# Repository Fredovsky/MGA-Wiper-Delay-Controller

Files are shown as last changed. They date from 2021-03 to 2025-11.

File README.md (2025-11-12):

# Classic Car Intermittent Wiper Motor Controller

A fully customizable, Arduino-based, multi-frequency intermittent wiper controller for classic British cars with single-speed Lucas DR2 wiper motors. This controller is non-destructive and fully reversible, requiring no modifications to the original vehicle.

## Overview

Some classic British cars such as the MG MGA and Triumph TR2 came equipped with a single-speed Lucas DR2 wiper motor. When encountering rain of various intensity, the single speed is just not appropriate 90% of the time. This project provides an intelligent controller that adds intermittent wiper functionality without modifying the original vehicle or requiring additional switches.

Video Title (https://www.youtube.com/watch?v=Cxpz3yVJnDE)

### Key Features

- **Non-destructive installation** - No modifications to the original vehicle
- **Uses factory switch** - No need for additional controls or multi-position switches
- **Multiple intermittent speeds** - Four configurable delay settings plus continuous mode
- **Intuitive control** - Quick ON-OFF-ON toggles to cycle through speeds
- **Compact design** - Small SMD-based PCB fits under the dashboard
- **Arduino-based** - Easy to program and customize
- **Fully reversible** - Can be removed and wiring restored to factory configuration

## The Problem

The Lucas DR2 wiper motor found in many classic British cars from the 1950s and 1960s operates at only a single, continuous speed. When driving through light rain at moderate/slow speeds, this continuous wiping motion is often too frequent. Many drivers end up manually switching the wipers ON and OFF repeatedly to achieve the desired intermittent wiping - this project automates that process.

### Original Wiper System

The factory wiper system has three terminals:
- **Terminal 2**: Continuous +12V power
- **Terminal 1**: Ground connection via dashboard switch
- **Terminal E**: Auto-parking ground connection

When the dashboard switch grounds terminal 1, the motor starts. The motor continues running via terminal E until the wipers return to their parked position, regardless of the switch position. If the switch is still closed when parked, wiping continues; otherwise, the motor stops.

## Solution

This controller sits between the original dashboard switch and the wiper motor, interpreting the switch position to provide multiple intermittent wiper modes. The driver uses quick ON-OFF-ON toggles of the original switch to cycle through different intermittent speeds.

### Operation Modes

The controller provides five operating modes:

1. **Intermittent 1**: Wipes every 10 seconds (slowest)
2. **Intermittent 2**: Wipes every 7.5 seconds
3. **Intermittent 3**: Wipes every 5 seconds
4. **Intermittent 4**: Wipes every 2.5 seconds
5. **Continuous**: Original single-speed operation (fastest)

### User Interface

- **Activate wipers**: Pull the switch ON to start wipers at the slowest intermittent setting
- **Increase speed**: Quickly toggle the switch OFF then ON (within 2 seconds) to advance to the next faster setting
- **Turn off wipers**: Push the switch OFF and hold for more than 2 seconds to deactivate and reset
- **Next activation**: Always starts at the slowest intermittent setting after a reset

## Hardware Design

### Architecture

The controller consists of three main sections:

1. **Power Regulation**: 12V to 5V conversion for microcontroller operation
2. **Microcontroller**: ATtiny85 running Arduino framework code
3. **Relay Driver**: High-current relay to control the wiper motor (5-10A capability)

### Components

#### Main Components

| Component | Part Number | Description | Quantity |
|---|---|---|---|
| **Microcontroller** | ATtiny85-20SU | 8-bit MCU, 8K Flash, Arduino compatible | 1 |
| **Voltage Regulator** | LM2931DT-5.0G | 5V 100mA LDO with load dump protection | 1 |
| **Relay** | V23076A1001C133 | Automotive power relay | 1 |
| **Transistor** | BC846BLT1G | NPN transistor for relay driver | 1 |
| **Optocoupler** | SFH6186-3T | Isolation for switch input | 1 |

#### Passive Components

| Component | Part Number | Description | Quantity |
|---|---|---|---|
| **Ferrite Beads** | FBMJ2125HS420-T | 0805 42Ω current chip bead | 2 |
| **Rectifier Diodes** | CGRTS4007-HF | 1000V 1A SMD rectifier | 2 |
| **Zener Diode** | SZMMSZ33ET1G | 33V 0.5W voltage regulator | 1 |
| **C1** | C0603C473K3RACTU | 0.047µF 25V X7R 0603 | 1 |
| **C2** | CGA4J1X7S1E106K125AC | 10µF 25V 0805 | 1 |
| **C3** | GRM21BC71C106KE11L | 10µF 16V X7S 0805 | 1 |
| **C4** | 35ZLH100MEFC6.3X11 | 100µF electrolytic capacitor | 1 |
| **C5, C6** | C0603C104K3RAC3190 | 0.1µF 25V X7R 0603 | 2 |
| **R1** | CRGP2512F470R | 470Ω 1% 2512 SMD | 1 |
| **R2, R3** | ERJ-3EKF1002V | 10kΩ 1% 0603 | 2 |
| **R4** | ERJ-3EKF1001V | 1kΩ 1% 0603 | 1 |

#### Connectors

| Component | Part Number | Description | Quantity |
|---|---|---|---|
| **J1-J4** | 7799 | M4 screw terminals | 4 |
| **J5** | 10129381-906004BLF | 2×3 ISP programming header | 1 |

### PCB Design

The PCB uses primarily SMD components to minimize size and was designed to potentially mount directly to the wiper motor housing. The final implementation installs under the dashboard where it remains virtually invisible while maintaining the stock appearance of the vehicle.

**PCB Specifications:**
- Compact two-layer design
- SMD components (0603/0805) where possible
- Through-hole components for high-current connections
- ISP programming header for easy firmware updates

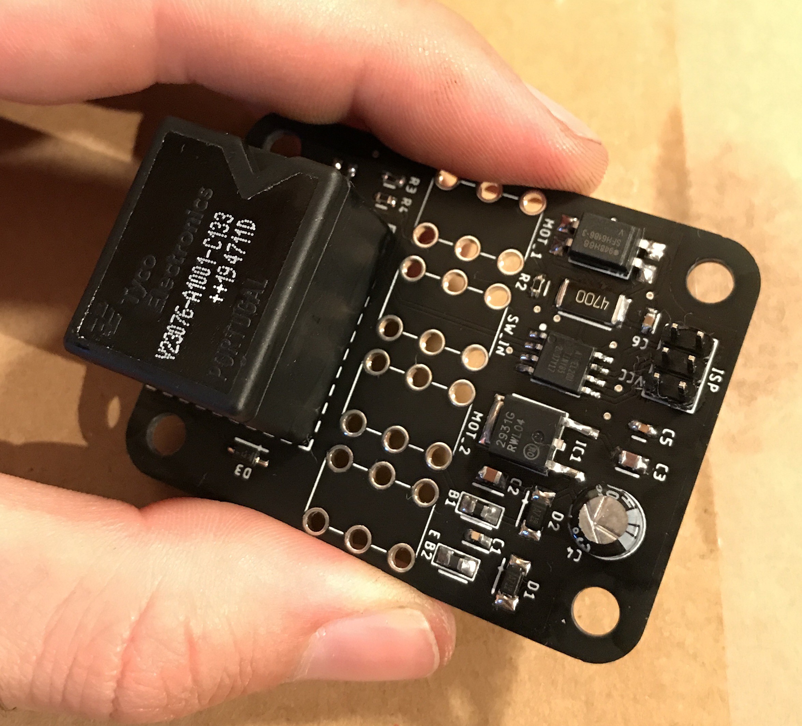
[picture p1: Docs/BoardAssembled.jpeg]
PCB Assembled


### Enclosure

The controller is housed in a two-part snap-fit enclosure designed in Fusion 360. Originally intended to mount on the wiper motor housing, the final installation places it under the dashboard for easier access and installation.

## Software

The controller is programmed using the Arduino framework with the ATtiny85 core. The code implements:

- **Switch debouncing** in software (50ms delay)
- **Non-blocking timing** using `millis()` instead of `delay()`
- **Toggle detection** to cycle through intermittent speeds

### Key Parameters

```cpp
// I/O Configuration
#define PIN_WIPER_OUTPUT 3          // Relay control pin
#define PIN_INPUT_SWITCH 4          // Dashboard switch input pin
#define SWITCH_DEBOUNCE_DELAY_MS 50 // Debounce delay
#define TOGGLE_LIMIT_DELAY 2000     // Max time for toggle detection

// Intermittent Delays
#define INTERMITTENT_1_MS 10000     // 10 seconds
#define INTERMITTENT_2_MS 7500      // 7.5 seconds
#define INTERMITTENT_3_MS 5000      // 5 seconds
#define INTERMITTENT_4_MS 2500      // 2.5 seconds

// Motor Control
#define RELAY_TIME_MS 500           // Relay activation duration
```

### Software Architecture

The software consists of two main functions:

#### `loop()` Function
- Reads the dashboard switch state
- Implements software debouncing
- Detects state changes (ON→OFF, OFF→ON)
- Tracks toggle sequences to determine mode changes

#### `wipe()` Function
- Executes wiper control based on current mode
- Manages timing for intermittent delays
- Controls relay activation/deactivation

### Customization

The intermittent delays can be easily customized by modifying the `INTERMITTENT_X_MS` definitions. The values are in milliseconds, so adjusting them to your preference is straightforward.

## Installation

### Wiring

The controller installs inline between the original wiring harness and the wiper motor:

**Input (from vehicle harness):**
- J1: Ground from dashboard switch
- J2: +12V power
- J3: Parking switch connection

**Output (to wiper motor):**
- J3: To motor terminal 1
- J2: To motor terminal 2 (through controller)
- J4: To motor terminal E

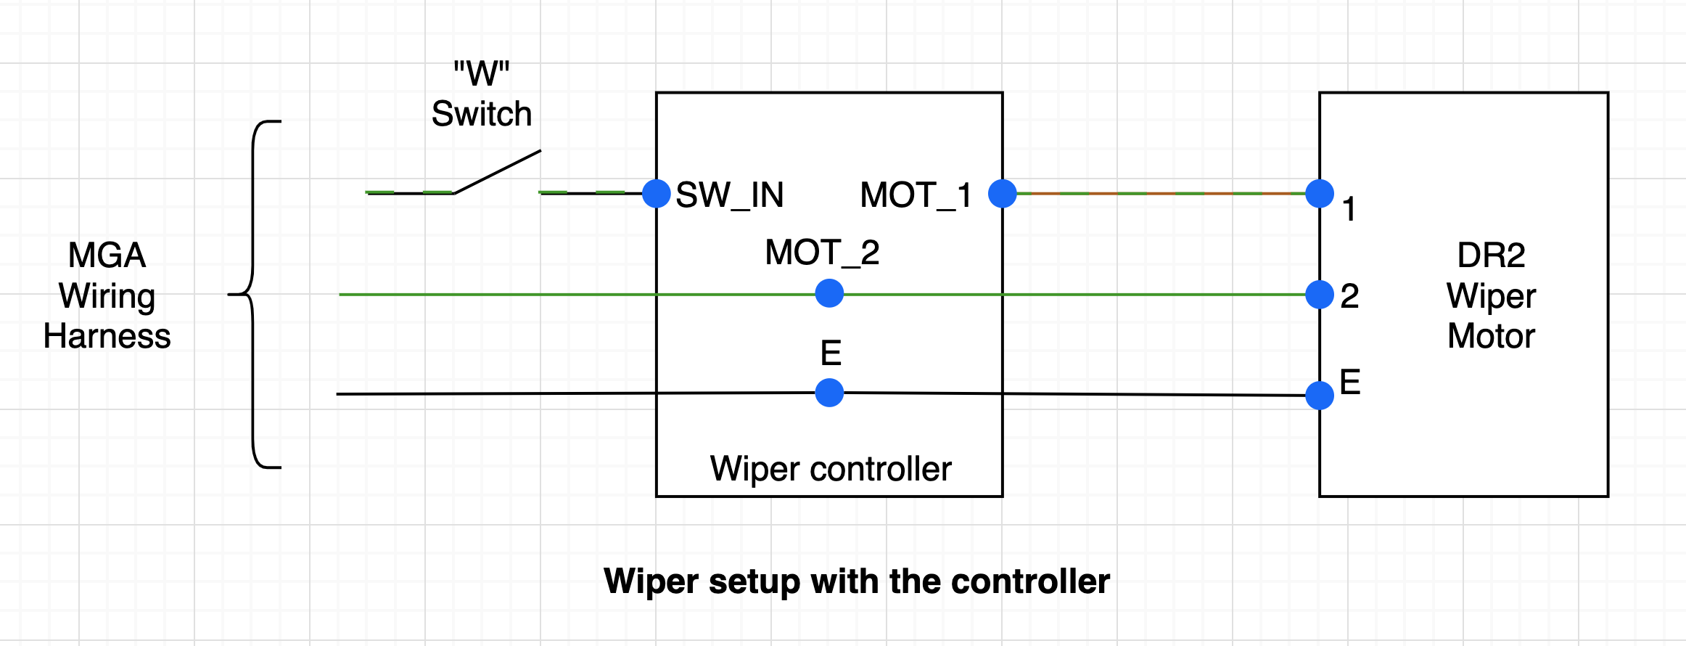
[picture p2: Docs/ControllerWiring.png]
PCB Wiring

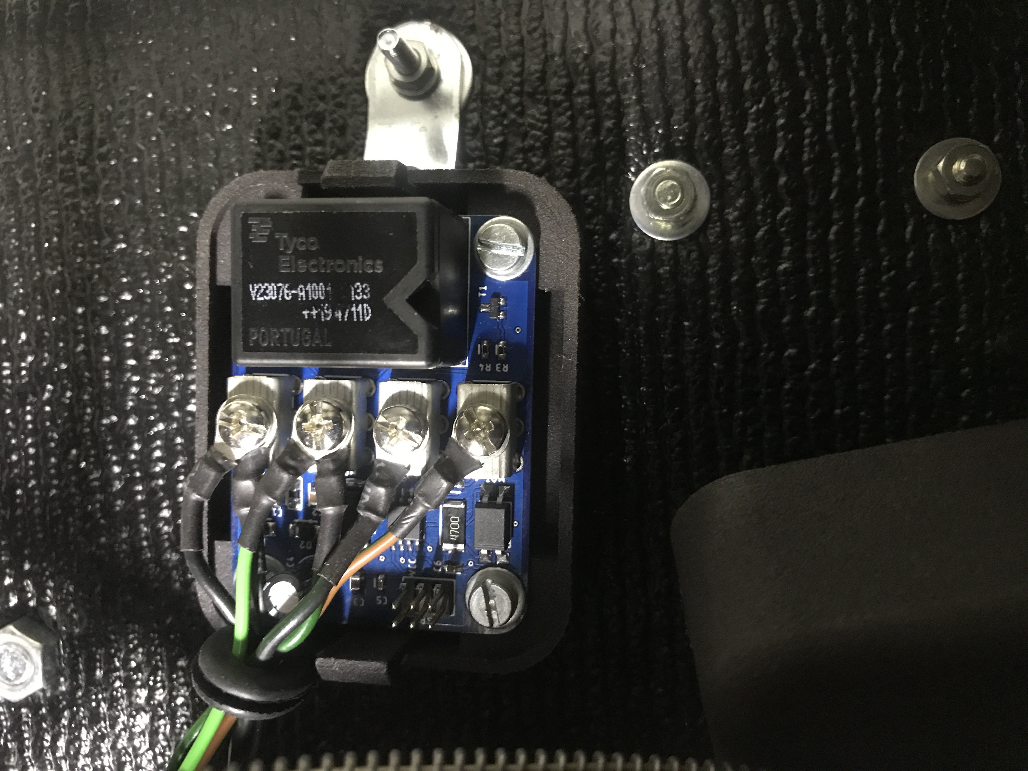
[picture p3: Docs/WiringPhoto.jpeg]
PCB Wiring Photo


### Programming

The ATtiny85 can be programmed via the ISP header (J5) using:
- USBasp programmer
- Arduino as ISP
- Other AVR programmers supporting ISP protocol

Flash the provided Arduino sketch to the ATtiny85 using the ISP connector on the PCB.

### Physical Installation

1. Disconnect the battery negative terminal
2. Locate the wiper motor and disconnect the original three-wire connector
3. Connect the controller inline between the harness and motor
4. Mount the controller under the dashboard using zip ties or mounting brackets
5. Reconnect the battery and test operation

## Testing

After installation, verify operation:

1. **Power on**: Pull the wiper switch - wipers should activate in slowest intermittent mode
2. **Toggle test**: Quickly switch OFF then ON - wipers should advance to next speed
3. **All modes**: Cycle through all five modes to verify each speed
4. **Reset**: Hold switch OFF for 3+ seconds, then reactivate - should start at slowest speed
5. **Parking**: Turn off in any mode - wipers should return to parked position

## Performance

The controller has been successfully tested and installed in an MG MGA. Key observations:

- **Reliable operation**: No false triggers or missed toggles
- **Proper timing**: All intermittent delays work as programmed
- **Original functionality preserved**: Can be removed without trace
- **Invisible installation**: Maintains stock appearance

## Files and Resources

All project files are available in this repository:
- `PlatformIO/` - Arduino source code
- `Eagle/` - Schematics, PCB layouts (+Gerber files)
- `Enclosure/` - 3D printable enclosure designs (STL/STEP files)

## Bill of Materials

Complete BOM with supplier part numbers is available in the `Eagle/BOM_Wiper_Control.pdf` file. All components are readily available from Mouser Electronics and other major suppliers.

## Requirements

### Hardware Requirements
- Classic car with Lucas DR2 or similar single-speed wiper motor
- Original single-pole ON-OFF wiper switch
- 12V electrical system

### Software Requirements
- Arduino IDE or PlatformIO
- ATtiny core support (install via Board Manager)

### Programming Tools
- AVR programmer with ISP support (USBasp or Arduino ISP programmer)
- 6-pin ISP cable

## Design Considerations

### Non-Destructive Philosophy
Every aspect of this design prioritizes reversibility:
- No cutting or drilling of original components
- No permanent wiring modifications
- No changes to dashboard or switch
- Controller can be completely removed, returning vehicle to factory specification

### Automotive Environment
The design accounts for the harsh automotive environment:
- Load dump protection in voltage regulator
- Automotive-grade relay rated for motor inrush current
- Ferrite beads for EMI suppression
- Proper wire gauge for current handling

### Safety
- Relay rated well above motor current draw
- Fused power connection recommended
- Isolated optocoupler for switch input
- Zener diode for voltage spike protection

## Compatibility

This controller is designed for the Lucas DR2 wiper motor but should work with any single-speed wiper motor that uses a similar three-wire configuration with auto-parking functionality. Confirm your motor's wiring matches before installation.

**Known compatible vehicles:**
- MG MGA (1955-1962)
- Triumph TR2 (1953-1955)
- Triumph TR3 (1955-1962)
- Other British cars from the 1950s-1960s with Lucas DR2 motors

## Contributing

Contributions are welcome! If you've installed this controller in a different vehicle or made improvements to the design, please submit a pull request or open an issue.

## License

This project is licensed under the **Creative Commons Attribution-NonCommercial-ShareAlike 4.0 International License (CC BY-NC-SA 4.0)**.

### You are free to:
- **Share** — copy and redistribute the material in any medium or format
- **Adapt** — remix, transform, and build upon the material

### Under the following terms:
- **Attribution** — You must give appropriate credit, provide a link to the license, and indicate if changes were made
- **NonCommercial** — You may not use the material for commercial purposes
- **ShareAlike** — If you remix, transform, or build upon the material, you must distribute your contributions under the same license

### What this means:
✅ **Allowed:**
- Personal use and modifications
- Educational purposes
- Sharing with the classic car community
- Building your own controller for your vehicle
- Sharing improvements and modifications

❌ **Not Allowed:**
- Selling the controller or kits commercially
- Manufacturing for profit
- Including in commercial products or services
- Using the design in commercial automotive products

**Full License:** [CC BY-NC-SA 4.0](https://creativecommons.org/licenses/by-nc-sa/4.0/)



## Acknowledgments

- **MGAGuru** for excellent wiper motor documentation
- **Arduino community** for ATtiny85 core support
- **Hackaday.io community** for feedback and encouragement

## Author

Created by F. Lidove for the classic car community.

Hackaday.io Project: https://hackaday.io/project/175605-classic-car-intermittent-wiper-motor-controller

## Disclaimer

This modification involves working with automotive electrical systems. While designed to be safe and reversible, improper installation could potentially damage your vehicle's electrical system. Install at your own risk. The author assumes no liability for any damage resulting from the use of this design.

Always disconnect the battery before working on automotive electrical systems.

## Support

For questions, issues, or discussions:
- Open an issue on this GitHub repository
- Comment on the Hackaday.io project page

---

*Enjoy safer driving in light rain with your classic British car!*

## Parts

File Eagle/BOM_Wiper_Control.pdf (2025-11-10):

WIPER CONTROL
N° Mouser | N° de fab. | Fabricant | N° client | Description
863-SZMMSZ33ET1G | SZMMSZ33ET1G | onsemi | D3 | Diodes Zener REG 0.5W 33V SPCL
963-FBMJ2125HS420-T | FBMJ2125HS420-T | TAIYO YUDEN | FB1 FB2 | Perles de ferrite 963-LSMCC201208T420R RPLCMT PN 0805 42OHMS 25%
750-CGRTS4007-HF | CGRTS4007-HF | Comchip Technology | D1 D2 | Redresseurs SMD 1000V 1A
863-LM2931DT-5.0G | LM2931DT-5.0G | onsemi | IC1 | Régulateurs de tension LDO 5V 100mA w/Load Dump
232-35ZLH100MEFC63X1 | 35ZLH100MEFC6.3X11 | Rubycon | C4 | Condensateurs électrolytiques en aluminium - Fils radiaux LOW IMPEDANCE ELECTROLYTIC CAPACITORS
810-CGA4J1X7S1E106K1 | CGA4J1X7S1E106K125AC | TDK | C2 | Condensateurs céramique multicouches MLCC - CMS 0805 25VDC 10uF 10% AEC-Q200
81-GRM21BC71C106KE1L | GRM21BC71C106KE11L | Murata | C3 | Condensateurs céramique multicouches MLCC - CMS 10 uF 16 VDC 10% 0805 X7S
556-ATTINY85-20SU | ATTINY85-20SU | Microchip | U1 | Microcontrôleurs 8 bits - MCU AVR 8K FLSH 512B EE 512B SRAM ADC 5V
80-C0603C104K3R3190 | C0603C104K3RAC3190 | KEMET | C5 C6 | Condensateurs céramique multicouches MLCC - CMS 25V 0.1uF X7R 0603 10% AEC-Q200
571-V23076A1001C133 | V23076A1001C133 | TE Connectivity | RL1 | Relais pour automobile Power Relay K
80-C0603C473K3R | C0603C473K3RACTU | KEMET | C1 | Condensateurs céramique multicouches MLCC - CMS 25V 0.047uF X7R 0603 10%
667-ERJ-3EKF1001V | ERJ-3EKF1001V | Panasonic | R4 | Résistances à couches épaisses - CMS 0603 1Kohms 1% AEC-Q200
863-BC846BLT1G | BC846BLT1G | onsemi | T1 | Transistors bipolaires - BJT 100mA 80V NPN
649-1012938190604BLF | 10129381-906004BLF | Amphenol | J5 | Embases et logements de câbles ECONOSTIK HEADER DR VT TH 2X3
667-ERJ-3EKF1002V | ERJ-3EKF1002V | Panasonic | R2 R3 | Résistances à couches épaisses - CMS 0603 10Kohms 1% AEC-Q200
782-SFH6186-3T | SFH6186-3T | Vishay | OK1 | Optocoupleurs de sortie de transistor Phototransistor Out Single CTR 100-200%
279-CRGP2512F470R | CRGP2512F470R | TE Connectivity | R1 | Résistances à couches épaisses - CMS CRGP 2512 470R 1% SMD Resistor
563-CU-18425-B | CU-18425-B | Bud Industries | ENCL | Boîtiers, boîtes et coffrets Snap Utility Box Black (2.8 X 2 X 1.7 In)
534-7799 | 7799 | Keystone Electronics | J1-J4 | Bornes M4 Screw term- H.D.

1

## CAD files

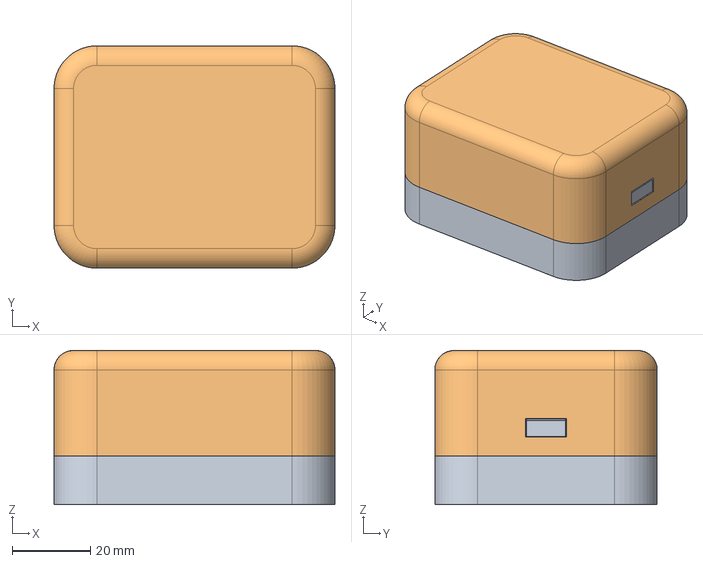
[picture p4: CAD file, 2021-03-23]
Enclosure/Snap Fit Box.stp
72.0 x 57.0 x 39.5 mm

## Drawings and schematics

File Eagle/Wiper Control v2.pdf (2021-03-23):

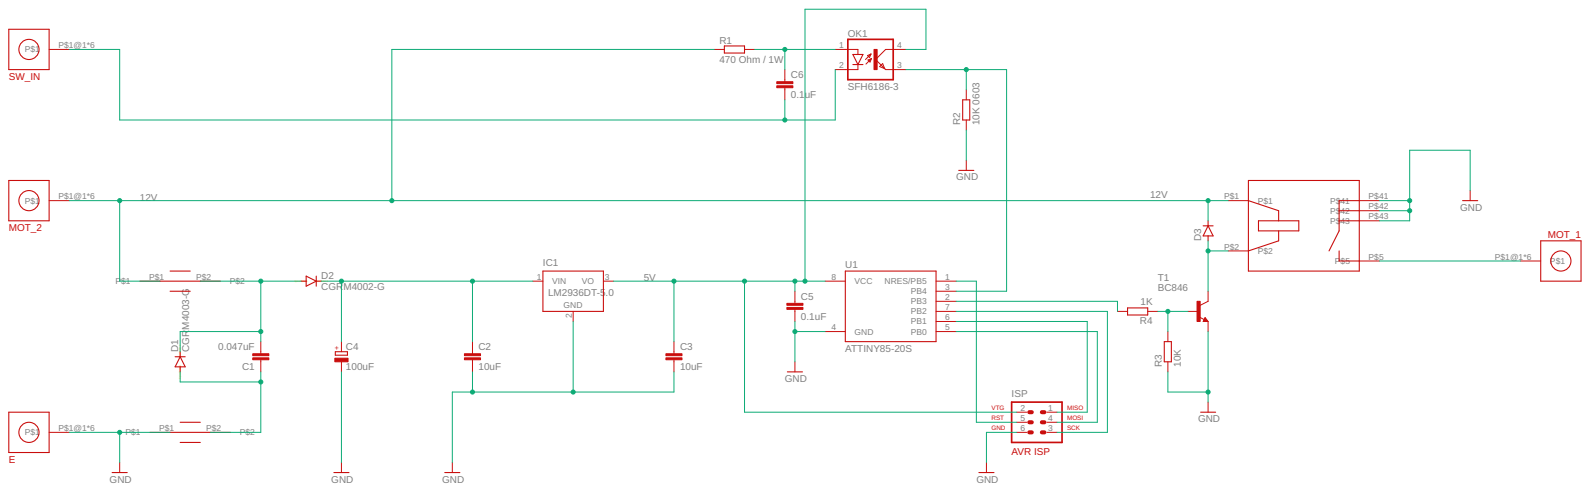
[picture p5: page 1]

SpiceOrder 1 SpiceOrder 2 SpiceOrder 1 SpiceOrder 2 LM2936DT-5.0 CGRM4003-G 0.047uF CGRM4002-G 10uF 10uF GND GND 100uF GND ATTINY85-20S GND GND 0.1uF BC846 GND SFH6186-3 GND 470 Ohm / 1W 10K 0603 10K 1K 0.1uF GND GND VIN 1 VO 3 2 IC1 P$1 P$1 P$2 P$2 P$1 P$1 P$2 P$2 D1 C1 D2 C4 C2 C3 PB0 5 PB1 6 PB2 7 PB3 2 PB4 3 NRES/PB5 1 VCC 8 GND 4 U1 3 25 1 6 4 ISP C5 P$1 P$1 P$2 P$2 P$41 P$41 P$5 P$5 P$42 P$42 P$43 P$43 T1 12 34 OK1 R1 R2 D3 R3 R4 C6 P$1 P$1@1*6 P$1 P$1@1*6 P$1 P$1@1*6 P$1 P$1@1*6 5V 12V 12V + AVR ISP MOSI SCK VTG MISO RST GND EMOT_2 SW_IN MOT_1

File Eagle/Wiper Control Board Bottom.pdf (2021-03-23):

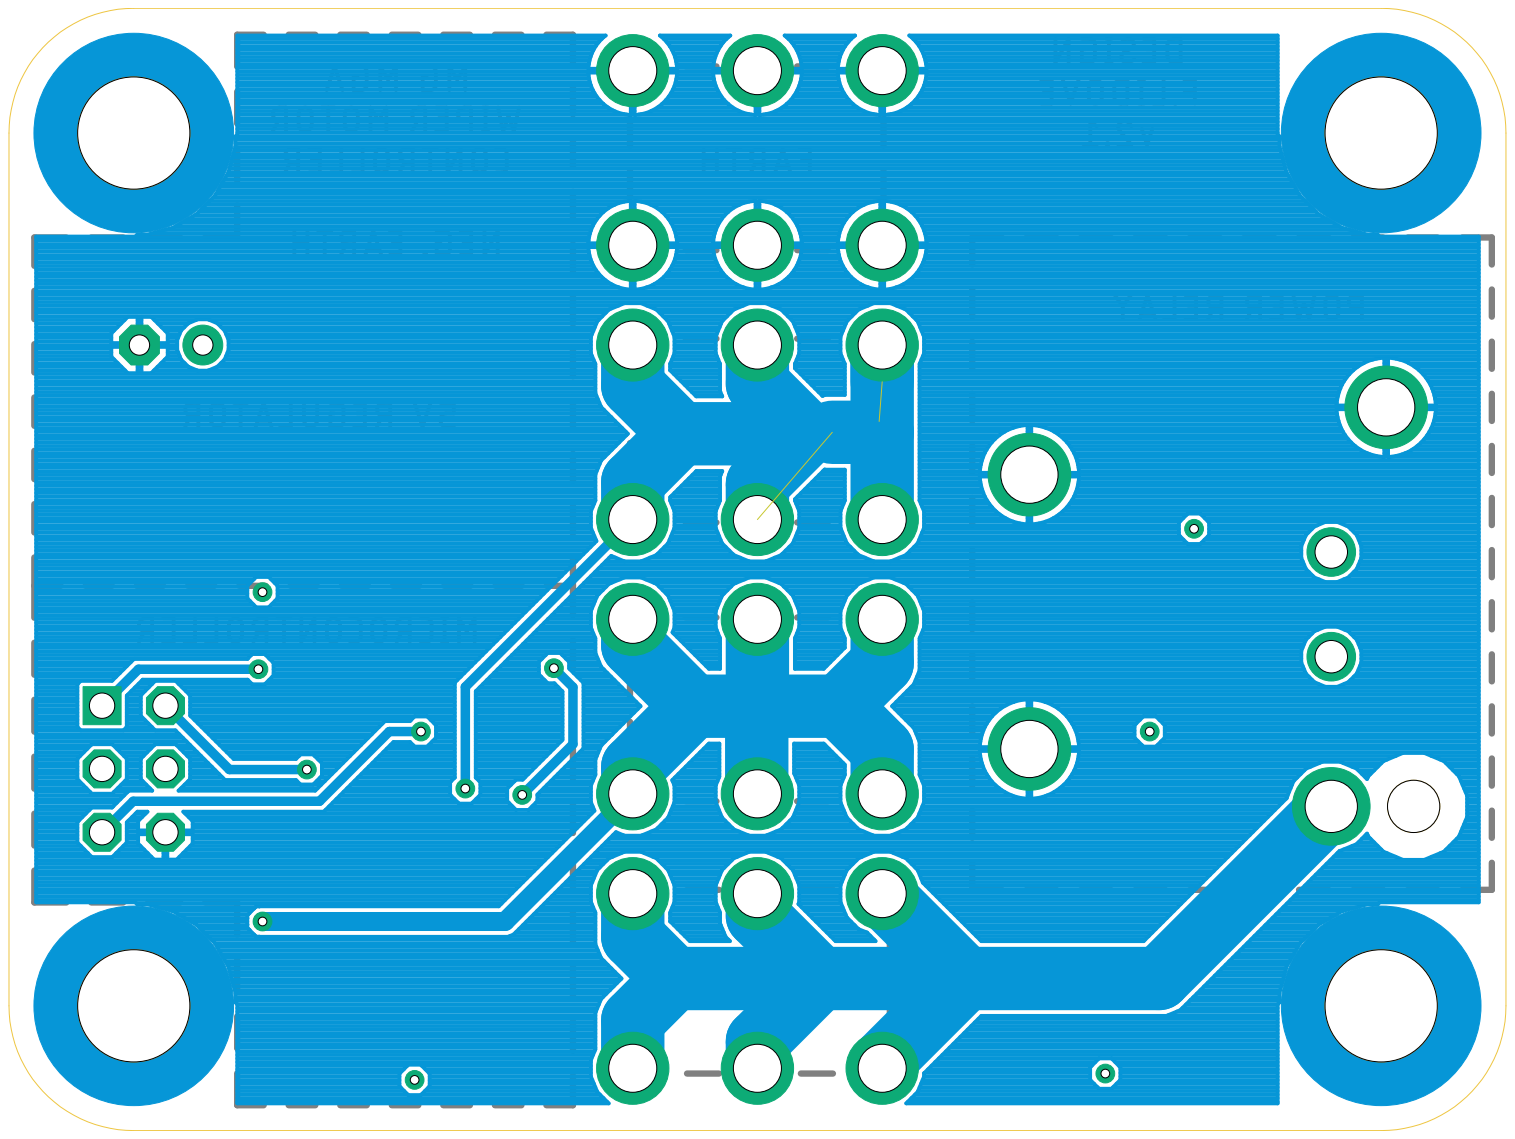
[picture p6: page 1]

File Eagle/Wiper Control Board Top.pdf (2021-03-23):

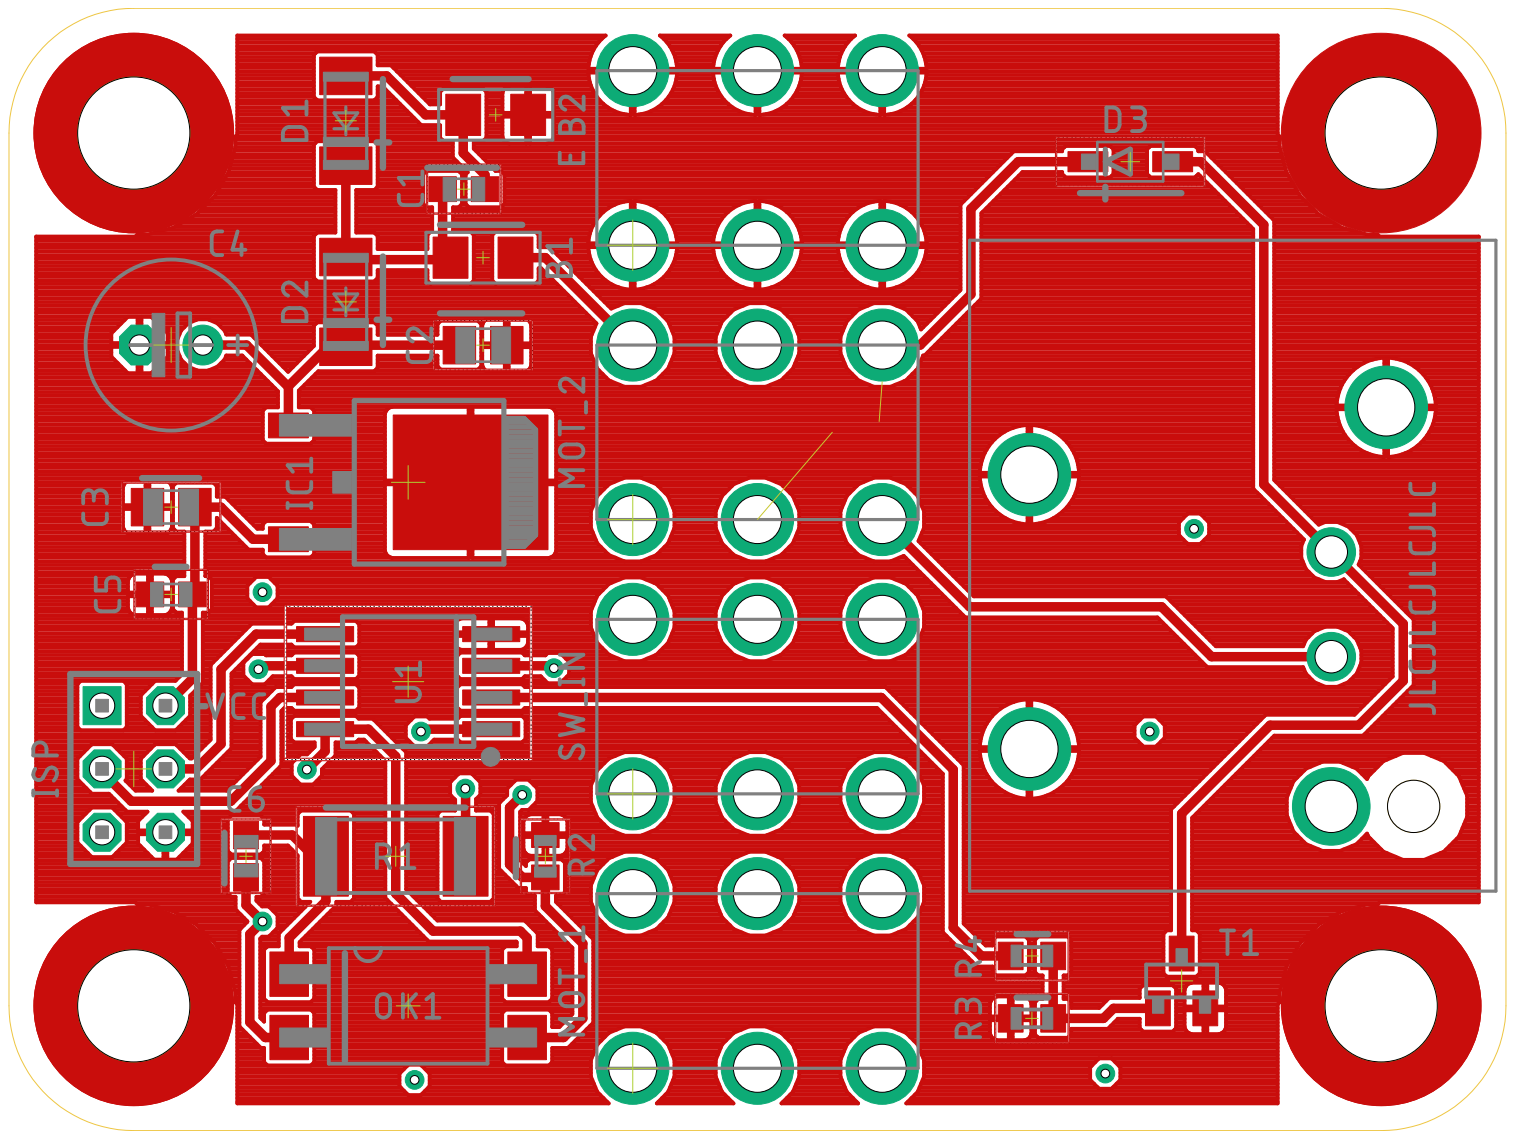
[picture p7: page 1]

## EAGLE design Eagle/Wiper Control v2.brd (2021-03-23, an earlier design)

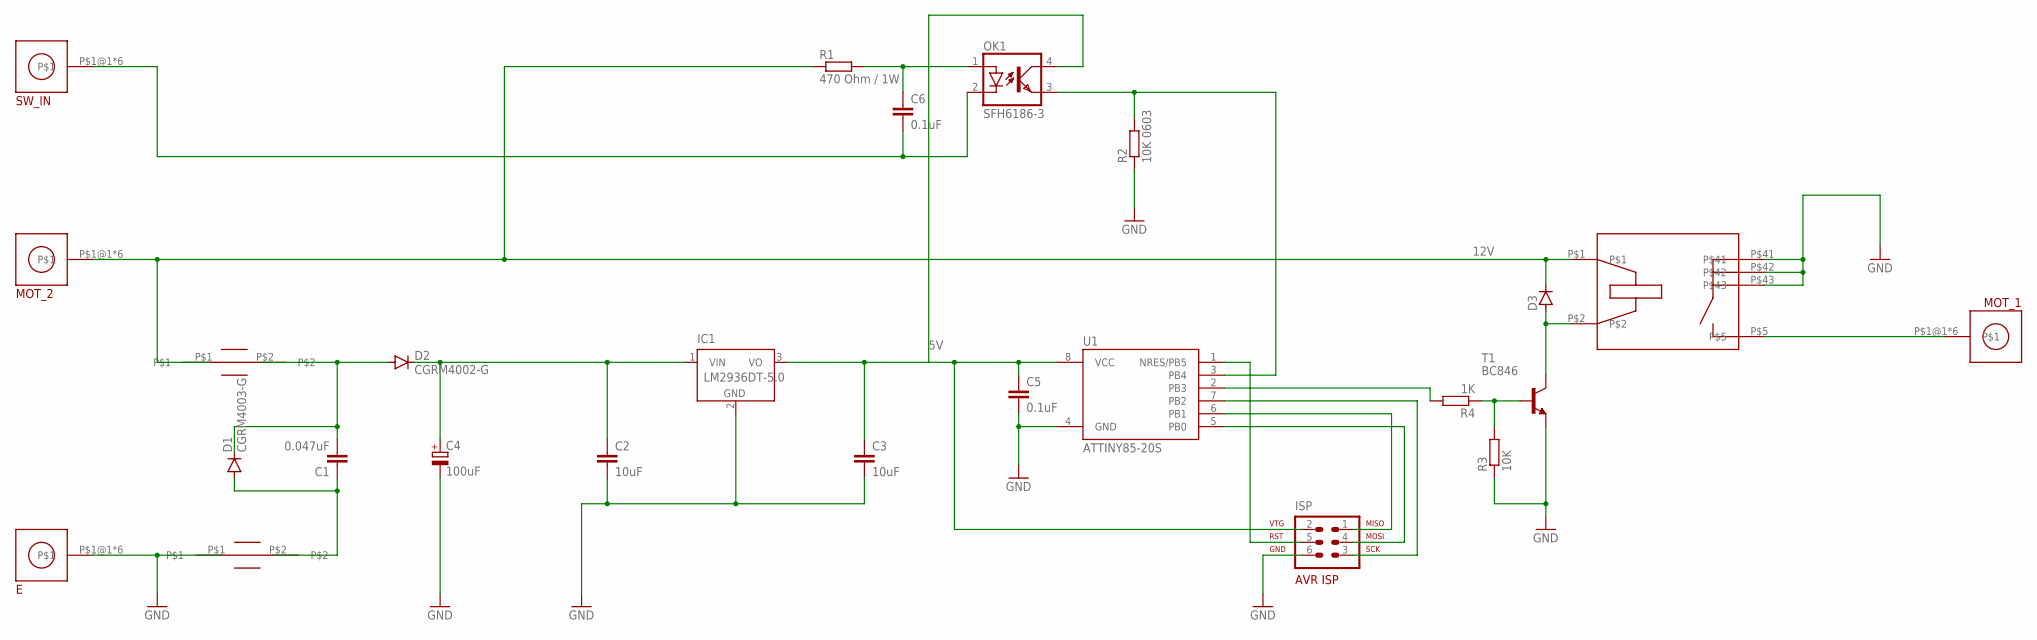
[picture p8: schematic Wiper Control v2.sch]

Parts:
B1, B2: FBMJ2125; FBMJ
C1: 0.047uF; C0603
C2, C3: 10uF; C0805
C4: 100uF; E2,5-7
C5, C6: 0.1uF; C0603
D1: CGRM4003-G; SOD-123_MINI-SMA
D2: CGRM4002-G; SOD-123_MINI-SMA
D3: D-SOD123; SOD123
E: M4_SCREW_TERMINAL
IC1: LM2936DT-5.0; TO252
ISP: AVR-ISP-6
MOT_1, MOT_2: M4_SCREW_TERMINAL
OK1: SFH6186-3; SMD4-7
R1: 470 Ohm / 1W; R2512
R2: 10K 0603; R0603
R3: 10K; R0603
R4: 1K; R0603
SW_IN: M4_SCREW_TERMINAL
T1: BC846; SOT23
U1: ATTINY85-20S; SOIC8_EIAJ_208MIL
U$3: RELAY

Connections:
5V: C3.1, C5.1, IC1.3 (VO), ISP.2, OK1.4 (COL), U1.8 (VCC)
12V: B1.P$1, D3.1 (C), MOT_2.P$1@1, MOT_2.P$1@2, MOT_2.P$1@3, MOT_2.P$1@4, MOT_2.P$1@5, MOT_2.P$1@6, R1.1, U$3.P$1
GND: B2.P$1, C2.2, C3.2, C4.-, C5.2, E.P$1@1, E.P$1@2, E.P$1@3, E.P$1@4, E.P$1@5, E.P$1@6, IC1.2 (GND), ISP.6, R2.1, R3.1, T1.2 (E), U1.4 (GND), U$3.P$41, U$3.P$42, U$3.P$43
unnamed: B1.P$2, C1.2, D1.C, D2.A
unnamed: B2.P$2, C1.1, D1.A
unnamed: C2.1, C4.+, D2.C, IC1.1 (VIN)
unnamed: ISP.1, U1.6 (PB1)
unnamed: ISP.4, U1.5 (PB0)
unnamed: ISP.3, U1.7 (PB2)
unnamed: ISP.5, U1.1 (NRES/PB5)
unnamed: D3.2 (A), T1.3 (C), U$3.P$2
unnamed: R3.2, R4.1, T1.1 (B)
unnamed: MOT_1.P$1@1, MOT_1.P$1@2, MOT_1.P$1@3, MOT_1.P$1@4, MOT_1.P$1@5, MOT_1.P$1@6, U$3.P$5
unnamed: C6.1, OK1.1 (A), R1.2
unnamed: OK1.3 (EMIT), R2.2, U1.3 (PB4)
unnamed: R4.2, U1.2 (PB3)
unnamed: C6.2, OK1.2 (C), SW_IN.P$1@1, SW_IN.P$1@2, SW_IN.P$1@3, SW_IN.P$1@4, SW_IN.P$1@5, SW_IN.P$1@6

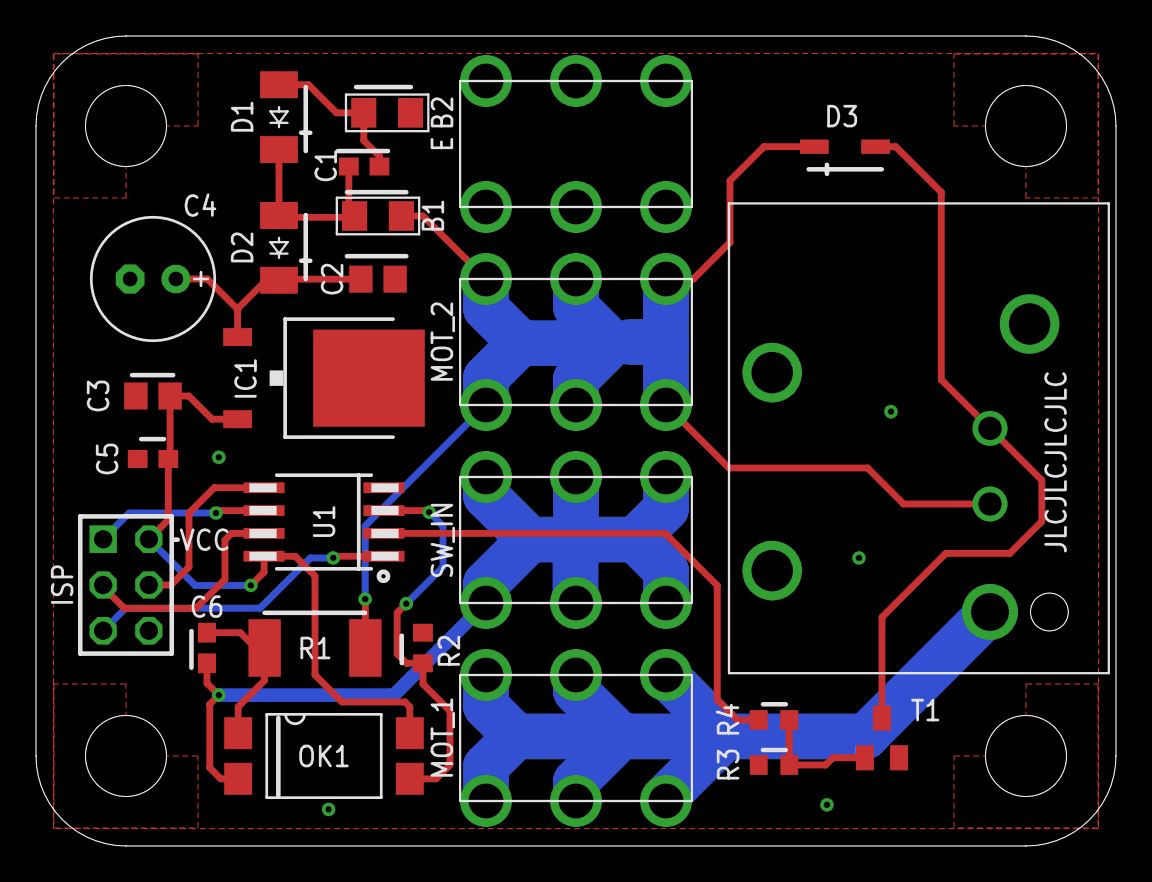
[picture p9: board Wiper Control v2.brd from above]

Board: 2 copper layers, 60.0 x 45.0 mm, 25 parts (1 on the bottom side), 17 nets.

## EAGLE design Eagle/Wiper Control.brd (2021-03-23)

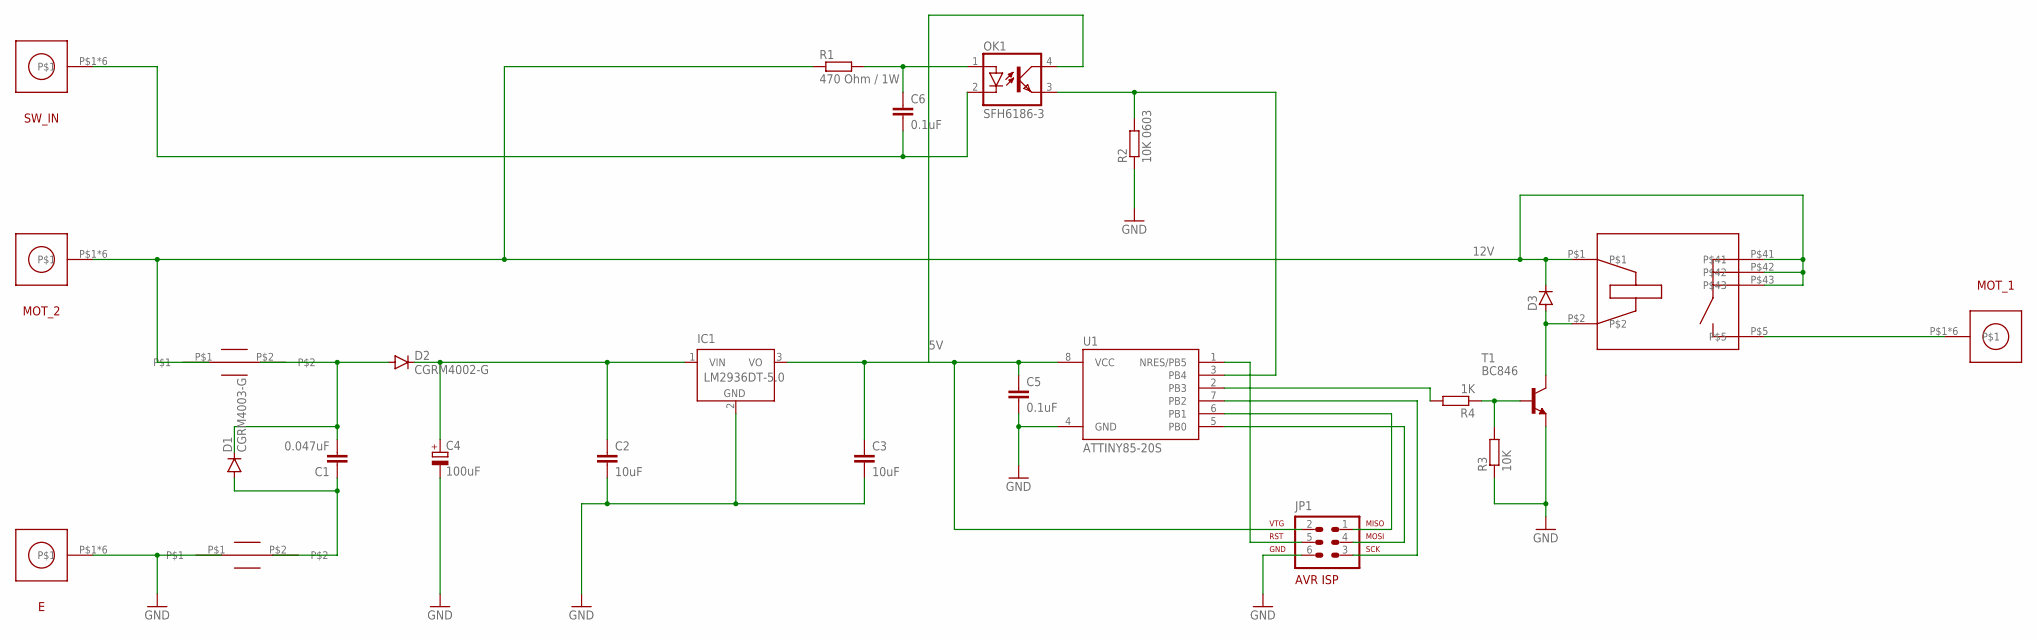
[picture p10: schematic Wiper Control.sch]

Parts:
C1: 0.047uF; C0603
C2, C3: 10uF; C0805
C4: 100uF; E2,5-7
C5, C6: 0.1uF; C0603
D1: CGRM4003-G; SOD-123_MINI-SMA
D2: CGRM4002-G; SOD-123_MINI-SMA
D3: D-SOD123; SOD123
E: M5_SCREW_TERMINAL
IC1: LM2936DT-5.0; TO252
JP1: AVR-ISP-6
MOT_1, MOT_2: M5_SCREW_TERMINAL
OK1: SFH6186-3; SMD4-7
R1: 470 Ohm / 1W; R2512
R2: 10K 0603; R0603
R3: 10K; R0603
R4: 1K; R0603
SW_IN: M5_SCREW_TERMINAL
T1: BC846; SOT23
U1: ATTINY85-20S; SOIC8_EIAJ_208MIL
U$1, U$2: FBMJ2125; FBMJ
U$3: RELAY

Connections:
5V: C3.1, C5.1, IC1.3 (VO), JP1.2, OK1.4 (COL), U1.8 (VCC)
12V: D3.1 (C), MOT_2.P$1, MOT_2.P$2, MOT_2.P$3, MOT_2.P$4, MOT_2.P$5, MOT_2.P$6, R1.1, U$1.P$1, U$3.P$1, U$3.P$41, U$3.P$42, U$3.P$43
GND: C2.2, C3.2, C4.-, C5.2, E.P$1, E.P$2, E.P$3, E.P$4, E.P$5, E.P$6, IC1.2 (GND), JP1.6, R2.1, R3.1, T1.2 (E), U1.4 (GND), U$2.P$1
unnamed: C1.2, D1.C, D2.A, U$1.P$2
unnamed: C1.1, D1.A, U$2.P$2
unnamed: C2.1, C4.+, D2.C, IC1.1 (VIN)
unnamed: JP1.1, U1.6 (PB1)
unnamed: JP1.4, U1.5 (PB0)
unnamed: JP1.3, U1.7 (PB2)
unnamed: JP1.5, U1.1 (NRES/PB5)
unnamed: D3.2 (A), T1.3 (C), U$3.P$2
unnamed: R3.2, R4.1, T1.1 (B)
unnamed: MOT_1.P$1, MOT_1.P$2, MOT_1.P$3, MOT_1.P$4, MOT_1.P$5, MOT_1.P$6, U$3.P$5
unnamed: C6.1, OK1.1 (A), R1.2
unnamed: OK1.3 (EMIT), R2.2, U1.3 (PB4)
unnamed: R4.2, U1.2 (PB3)
unnamed: C6.2, OK1.2 (C), SW_IN.P$1, SW_IN.P$2, SW_IN.P$3, SW_IN.P$4, SW_IN.P$5, SW_IN.P$6

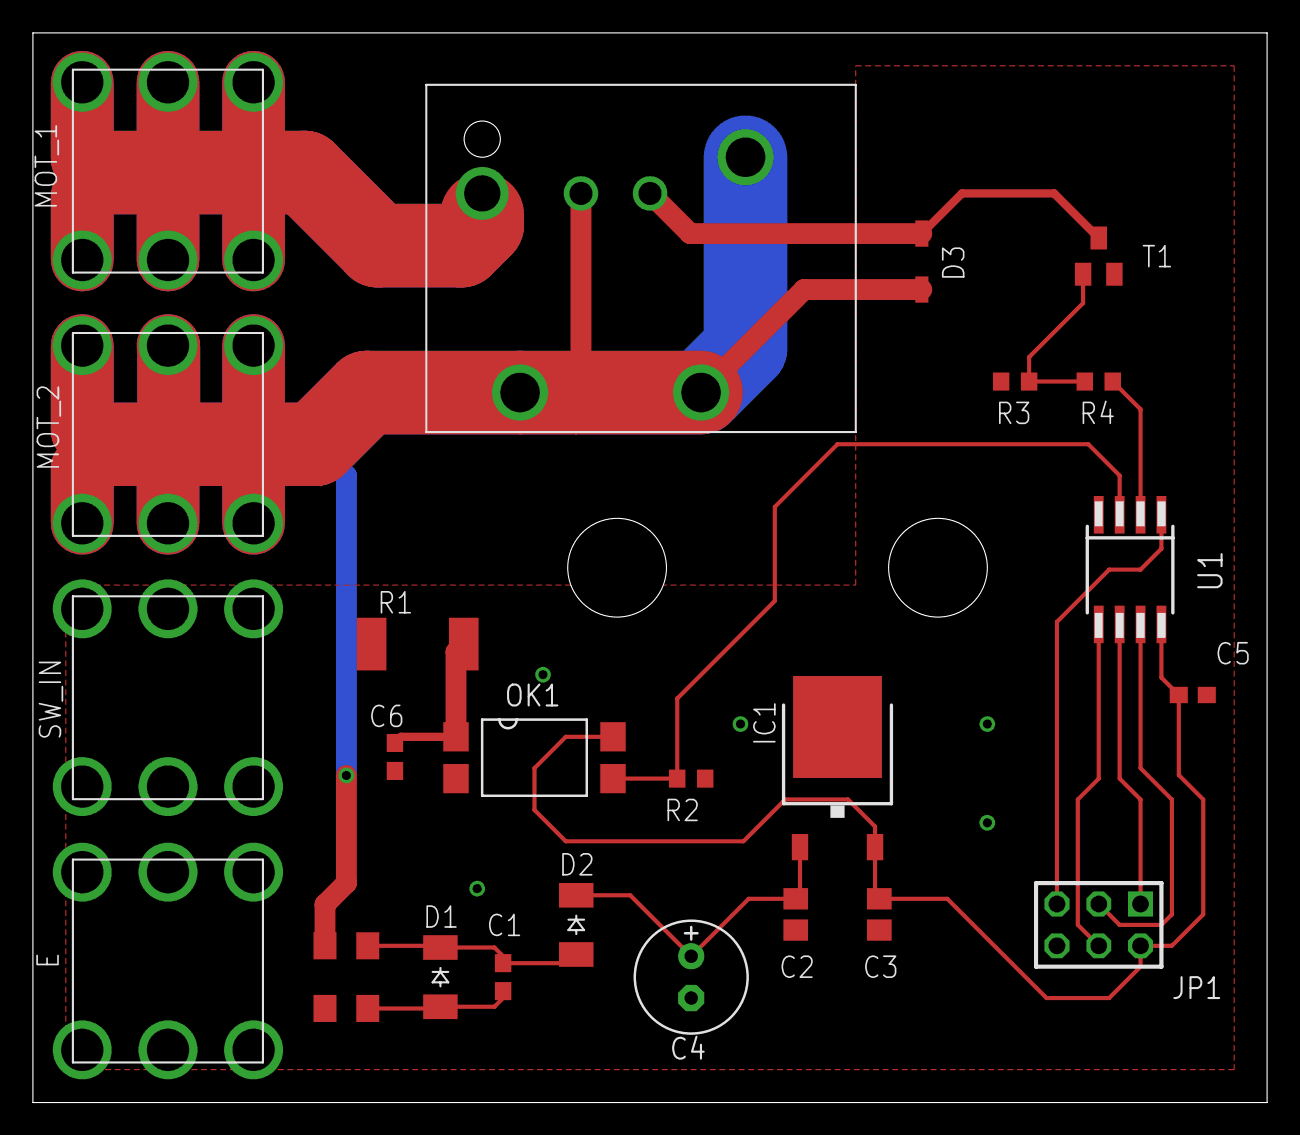
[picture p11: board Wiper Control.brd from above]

Board: 2 copper layers, 75.0 x 65.0 mm, 25 parts (0 on the bottom side), 17 nets.

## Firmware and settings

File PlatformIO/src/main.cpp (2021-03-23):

#include <Arduino.h>

/* I/O PARAMETERS */
#define PIN_WIPER_OUTPUT 3 // PIN to wiper relay
#define PIN_INPUT_SWITCH 4 // Pin reading wiper dashboard switch position
#define SWITCH_DEBOUNCE_DELAY_MS 50 // Switch debounce delay in ms
#define TOGGLE_LIMIT_DELAY 2000 // Time to consider an ON-OFF-ON as a toggle

/* INTERMITTENT CONTROL PARAMETERS */
#define INTERMITTENT_1_MS 10000 // Intermittent delay 1 in ms
#define INTERMITTENT_2_MS 7500 // Intermittent delay 2 in ms
#define INTERMITTENT_3_MS 5000 // Intermittent delay 3 in ms
#define INTERMITTENT_4_MS 2500 // Intermittent delay 4 in ms

/* WIPER MOTOR RELATED PARAMETERS */
#define RELAY_TIME_MS 500 // Duration (ms) the relay stays closed to initiate the wiper swipe

uint8_t toggles = 0; // Track the ON->OFF->ON toggles
uint8_t switchState = LOW; // Keep track of previous switch status
uint8_t lastSwitchState = LOW;   // the previous reading from the switch
uint8_t forceWipe = false;  // Force a wipe now
unsigned long lastWipeTime = 0;
unsigned long lastOffTime = 0;  // Last time the switch was in the OFF position
unsigned long lastDebounceTime = 0;  // the last time the switch was toggled
unsigned long debounceDelay = 50;    // the debounce time in ms

void setup() {
  // Initialize PIN modes
  pinMode(PIN_WIPER_OUTPUT, OUTPUT);
  pinMode(PIN_INPUT_SWITCH, INPUT);

  // If wiper switch ON at power up, activates wipers
  if(digitalRead(PIN_INPUT_SWITCH)){
    switchState = HIGH;
    lastSwitchState = HIGH;
  }
}

void wipe() {
  // Wipe outputs based on switch position and toggle numbers
  if(switchState == HIGH) {
    int intermittentDelay = 0;
    // Wipers are on
    switch (toggles) {
      case 0:
        intermittentDelay = INTERMITTENT_1_MS;
        break;
      case 1:
        intermittentDelay = INTERMITTENT_2_MS;
        break;
      case 2:
        intermittentDelay = INTERMITTENT_3_MS;
        break;
      case 3:
        intermittentDelay = INTERMITTENT_4_MS;
        break;
      default:
        // Continuous wipers
        intermittentDelay = 0;
        break;
    }

    if(millis()-lastWipeTime > intermittentDelay || forceWipe) {
      //Send a wipe pulse
      digitalWrite(PIN_WIPER_OUTPUT, HIGH);
      lastWipeTime = millis();
      forceWipe = false;
    }

    if(millis()-lastWipeTime > RELAY_TIME_MS) {
      // End the pulse after the required delay
      digitalWrite(PIN_WIPER_OUTPUT, LOW);
    }

  } else {
    // digitalWrite(PIN_WIPER_OUTPUT, LOW);
  }
}

void loop() {

  // read the state of the switch into a local variable:
  int reading = digitalRead(PIN_INPUT_SWITCH);

  // check to see if you just switched the button
  // and you've waited long enough
  // since the last change to ignore any noise:

  // If the switch changed, due to noise or pressing:
  if (reading != lastSwitchState) {
    // reset the debouncing timer
    lastDebounceTime = millis();
  }

  if ((millis() - lastDebounceTime) > debounceDelay) {
    // whatever the reading is at, it's been there for longer than the debounce
    // delay, so take it as the actual current state:

    // if the button state has changed:
    if (reading != switchState) {
      switchState = reading;

      // If ON to OFF detected
      if(switchState == LOW){
        lastOffTime = millis();
        digitalWrite(PIN_WIPER_OUTPUT, LOW); // Switch OFF the wipers (in case it's not a toggle, just an OFF action)
      }

      // If OFF to ON detected
      if(switchState == HIGH) {
        // Force a wipe as we either just switched on the wipers or are increasing the frequency
        forceWipe = true;
        if(millis()-lastOffTime < TOGGLE_LIMIT_DELAY) {
          // Toggle detected
          toggles++;
        } else {
          // Switching to ON only (not a toggle)
          toggles = 0;
        }
      }
    }
  }
lastSwitchState = reading;

// Finally...
wipe();
delay(10);
}

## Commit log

2021-03-23 Project creation.
    All files added. 3D printed box files on Fusion 360 cloud account.
    [Snap Fit Box.stp, Wiper Control v2.brd, Wiper Control v2.sch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]
2025-11-10 Add files via upload
    BOM added
2025-11-11 Revise README for Classic Car Wiper Controller
    Updated project details and expanded documentation for the Classic Car Intermittent Wiper Motor Controller, including installation instructions, hardware design, software architecture, and safety con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
2025-11-11 Update BOM file location in README
    Updated BOM location from hardware/BOM.csv to Eagle/BOM_Wiper_Control.pdf.
